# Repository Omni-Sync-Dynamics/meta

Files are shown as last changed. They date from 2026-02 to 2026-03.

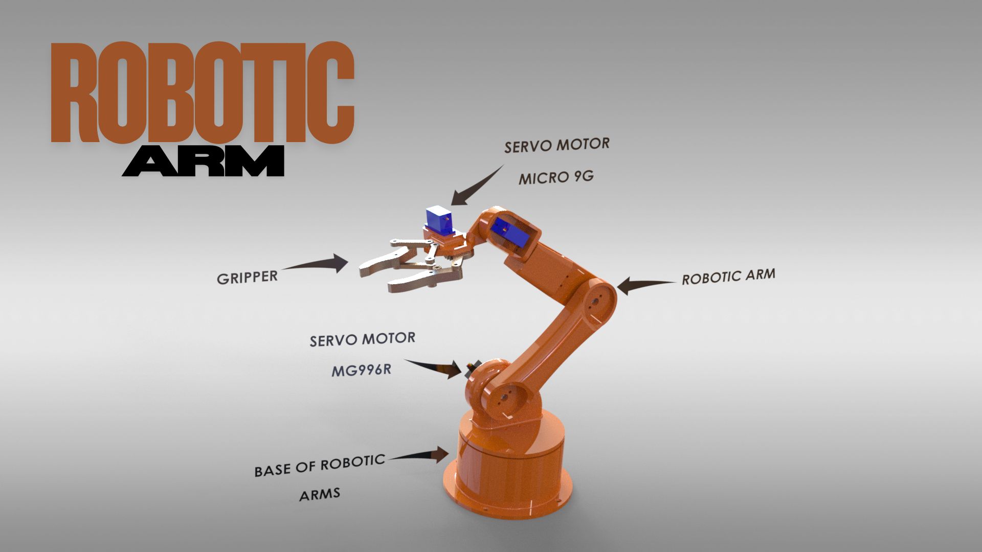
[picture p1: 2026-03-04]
Mechanical/robotic_arm_5dof/isometric_2.jpg

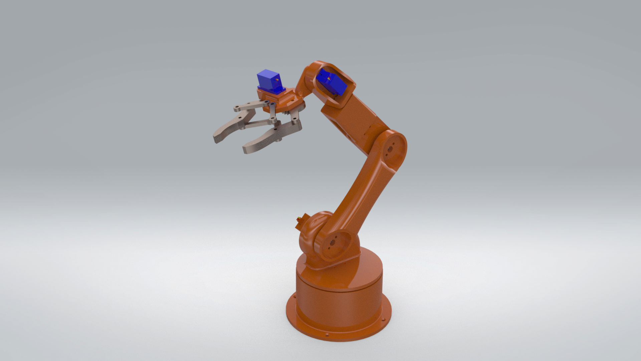
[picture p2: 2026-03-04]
Mechanical/robotic_arm_5dof/isometric.png

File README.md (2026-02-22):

# 🦾 Manipulator Subsystem - Omni-Wheel Mobile Manipulator

**Mechatronics Engineering Department | Faculty of Engineering, Ain Shams University**

This repository contains the mechanical, electrical, and software design files for the **Manipulator Subsystem (Arm & Gripper)** of the Modular Omni-Wheel Mobile Manipulator, developed for the **Spring 2026 Mechatronics Omni-Challenge**.
## 🔭 Overview

The Manipulator Module is designed as a standalone, professionally packaged subsystem. Its primary objective is to autonomously reach, grasp $5\times5\times5$ cm cubes encoded with QR codes from a 40 cm elevated pedestal, identify their color via an integrated camera, and securely place them into specific onboard storage bins.

It acts as the upper layer of the mobile robot and communicates seamlessly with the Mobile Base via a robust CAN/UART interface.

## ✨ Key Features

- **4-DOF Articulated Design:** Optimized to reach the 40 cm pedestal while folding completely within the strict $50\times50\times70$ cm global starting constraint.
    
- **Smart Serial Actuation:** Utilizes daisy-chained smart serial servos (e.g., Dynamixel/Feetech) with built-in absolute encoders and PID control to minimize weight and wire clutter.
    
- **Eye-in-Hand Perception:** Offset end-effector RGB camera paired with an active constant-current LED ring for flicker-free QR code decoding.
    
- **V-Shaped Interlocking Gripper:** Custom parallel-jaw gripper lined with high-friction silicone pads to ensure cubes are not dropped during aggressive omni-directional base maneuvers.
    
- **Custom Integration PCB:** Dedicated onboard PDU and MCU with hardware debouncing, CAN transceivers, and isolated motor power injection.

## 🛠 Hardware Specifications

|Specification|Target / Limit|Notes|
|---|---|---|
|**Degrees of Freedom**|4 (Base, Shoulder, Elbow, Wrist) + 1 (Gripper)|Focused on pick-and-place efficiency.|
|**Max Reach (Horizontal)**|$\ge 40$ cm|Measured from the base joint center.|
|**Payload Capacity**|$250$ g (Nominal) / $500$ g (Max)|For handling $5\times5\times5$ cm cubes.|
|**Module Weight**|$\le 3.0$ kg|Keeps total robot weight under 10 kg.|
|**Operating Voltage**|12V / 24V (Raw)|Stepped down locally to 5V/3.3V.|
|**Comms Protocol**|CAN Bus / RS-485|Optically isolated from motor noise.|

## 🔌 Plug-and-Play Integration

To meet the **< 5-minute integration** constraint, the arm interfaces with the mobile base via a strict modular boundary:

1. **Mechanical:** Chamfered alignment pins and a quick-release latch on the mounting plate.
    
2. **Power:** Single `XT60` or `Anderson Powerpole` connector delivering fused raw battery power.
    
3. **Data:** Single locking `JST-SM` or `Aviation` plug carrying the communication bus lines.
    
4. **Safety:** Software heartbeat watchdog. Loss of comms automatically freezes all servo joints.

## 📂 Repository Structure

```
📦 Manipulator-Subsystem
 ┣ 📂 CAD                 # SolidWorks/Fusion360 assemblies and STL files
 ┣ 📂 Electronics         # KiCAD/Altium schematics and PCB layout files
 ┣ 📂 Software            # ESP32/STM32 firmware (Kinematics, CAN, Safety)
 ┣ 📂 Perception          # Python vision scripts for QR/Color detection
 ┣ 📂 Docs                # VDI 2206 Documentation, FMEA, and Requirements
 ┗ 📜 README.md           # Project overview (This file)
```

## 📚 Documentation

Detailed engineering reports generated following the VDI 2206 methodology:

- [Requirements Analysis Document (`Docs/Requirements.pdf`)](https://www.google.com/search?q=./Docs/ "null")
    
- [System Architecture & FBD (`Docs/Architecture.md`)](https://www.google.com/search?q=./Docs/ "null")
    
- [FMEA Risk Assessment Report (`Docs/Risk_Assessment.pdf`)](https://www.google.com/search?q=./Docs/ "null")
    
- [Electromechanical Bill of Materials (BOM) (`Docs/BOM.pdf`)](https://www.google.com/search?q=./Docs/ "null")
    
- [Electrical & Electronics Architecture (`Docs/Electronics.pdf`)](https://www.google.com/search?q=./Docs/ "null")

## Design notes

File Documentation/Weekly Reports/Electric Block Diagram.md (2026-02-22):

```mermaid
flowchart LR

Battery --> Fuse
Fuse --> PowerBoard

PowerBoard --> MotorDriver1
PowerBoard --> MotorDriver2
PowerBoard --> MotorDriver3
PowerBoard --> MotorDriver4

PowerBoard --> VoltageRegulator

VoltageRegulator --> MCU
VoltageRegulator --> Sensors
VoltageRegulator --> Camera

MCU --> MotorDriver1
MCU --> MotorDriver2
MCU --> MotorDriver3
MCU --> MotorDriver4

Sensors --> MCU
Camera --> MCU
```

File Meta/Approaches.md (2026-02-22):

- Open source
- Mobile robot manipulators
- Omni-wheel platform
- Robotic arm
- Create performance index out of design requirements to compare between different solutions
- Design while learning
- Requirements -> Performance requirements -> FSD (general -> sub systems with reusable functions) -> block diagram and layout
- General brainstorming 
- Meta tasks
- Missing general tasks
- EDP

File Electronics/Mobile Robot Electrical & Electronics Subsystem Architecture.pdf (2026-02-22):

# Mobile Base Module: Electrical &

# Electronics Subsystem Architecture

This document outlines the functional sub-circuits required for the mobile base’s integrated PCB. Designing these as a cohesive onboard system ensures professional packaging, eliminates loose wires, and is strictly required to pass the Phase 1 Safety Check.

### 1 Control Panel Circuit (HMI)

This circuit manages the Human-Machine Interface directly on the robot chassis, handling physical operator inputs and providing immediate system status feedback.

- Mode Switches: Toggle or rotary switches to transition the state machine

between Manual Teleoperation and Autonomous Mode.

- Push Buttons: Hardware buttons (with RC debouncing circuits) for system

resets or specific execution commands.

- Status Indicators: LED arrays with current-limiting resistors to visually in-

dicate Power ON, Fault States, Communication Active, and current operating mode.

### 2 BMS (Battery Management System) Circuit

The BMS acts as the core health monitor for the battery pack. It prevents catastrophic electrical failures and ensures the power source operates within safe margins.

- BMS IC: A dedicated management chip (e.g., BQ series) to monitor individual

cell voltages continuously.

- Balancing Hardware: Cell balancing resistors and MOSFETs to ensure uni-

form voltage across all battery cells during charge and discharge cycles.

- Thermal Sensors: NTC Thermistors placed near the battery leads for real-time

temperature monitoring.

- Current Shunts: Sense resistors to track overall power consumption and detect

over-current stalls.

### 3 Recharging & Power Circuit

This section serves as the main power entry point, routing high current from the battery to the rest of the system while managing the mandatory safe charging approach.

- High-Current Connectors: Secure, polarized connectors (e.g., XT60 or XT90)

bridging the battery and the main board.

- Charge Controller: ICs managing the safe influx of current if onboard charging

is implemented.

- Power Path Management: Power MOSFETs configured to seamlessly and

safely switch between battery power and external wall power during tethered programming or testing.

### 4 Regulation Circuit

Batteries provide a fluctuating voltage that drops as they discharge. This circuit steps down the raw battery voltage into the stable, clean logic levels required by the MCU, sensors, and communication chips.

- Buck Converters (Switching Regulators): High-efficiency circuits (compris-

ing a control IC, inductor, diode, and smoothing capacitors) used to step down the raw battery voltage to a stable 5V for heavier logic loads.

- LDOs (Low Dropout Regulators): Linear regulators used to step down the

5V rail to a highly stable, low-noise 3.3V rail, which is critical for noise-sensitive components like the IMU and MCU.

### 5 Driver & Motor Circuit

This power electronics stage translates low-voltage logic signals from the MCU into high-current outputs to drive the omni-wheel drivechain. Similar to the rapid switching concepts used in AC motor drives, this DC circuit precisely controls speed and torque.

- Power Switching: H-Bridge ICs or discrete power MOSFET arrays to control

the bidirectional rotation of the DC motors.

- Gate Drivers: ICs designed to rapidly switch the MOSFET gates, minimizing

thermal switching losses.

- Flyback Protection: Freewheeling diodes placed across the motor outputs to

protect the circuit from damaging inductive voltage spikes.

- Decoupling: Large electrolytic and ceramic capacitors placed physically close

to the driver ICs to handle sudden, massive current spikes during rapid strafing maneuvers.

### 6 Safety & Protection Circuit

This is the mandatory hardware layer that acts as the ultimate failsafe for the robot. It protects the entire electronics stack from user errors, shorts, and mechanical stalls.

- Main Fuse: An automotive-style blade fuse correctly rated for the combined

maximum current draw of the mobile base and the manipulator.

- Emergency Stop (E-Stop): A physical, latching mushroom button wired di-

rectly in series with the main power line to immediately cut actuation power.

- Reverse Polarity Protection: A P-channel MOSFET or high-current Schot-

tky diode circuit preventing catastrophic damage if the battery is plugged in backward.

- Transient Protection: TVS (Transient Voltage Suppressor) diodes across power

and communication lines to clamp ESD and voltage spikes.

### 7 Sensor & Perception Circuit

This circuit serves as the bridge between the physical environment and the main processor, conditioning signals necessary for precise odometry and autonomous visual perception.

- Camera Interface: A high-speed data bus (such as USB, MIPI CSI, or ded-

icated ribbon connector) connecting an RGB/Depth camera to handle lane detection and color classification via QR code.

- Wheel Motor Encoders: Dedicated headers and signal conditioning (like hard-

ware logic level shifters or Schmitt triggers) to cleanly read high-frequency pulse trains from the quadrature encoders, essential for tracking pure X/Y translation.

- IMU (Inertial Measurement Unit): An onboard sensor IC (e.g., MPU6050)

communicating via I²C/SPI to provide heading stabilization and prevent unin-

tended rotation.

- Optional Interfaces: Headers for extra sensors like proximity/ToF or bump

sensors.

### 8 MCU & Communication Circuit (The Integration Layer)

This circuit houses the “brain” of the base module and the communication bus required for plug-and-play integration with the Manipulator Module.

- Microcontroller Unit (MCU): The primary processor (e.g., ESP32, STM32)

that executes the kinematic controller, state machine, and perception pipelines.

- Minimum System Components: The external crystal oscillator (clock), boot

configuration resistors, and reset circuitry required for the MCU to function.

- Communication Transceivers (COM Circuit): ICs specific to your chosen

protocol (e.g., CAN transceiver like the MCP2551, or RS-485 driver) to enable a robust comms bus between the base and the arm.

- Isolation: Opto-isolators to electrically separate logic signals between the base

and manipulator, preventing ground loops and motor noise from corrupting data.

- Standardized Connectors: Locking headers (e.g., Molex or JST) forming the

physical standardized electrical interface for the plug-and-play requirement.

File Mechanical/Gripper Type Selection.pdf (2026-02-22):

## Gripper Type Selection

Gripper types
1) Parallel jaw

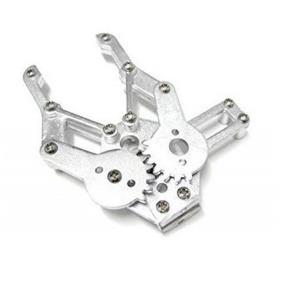
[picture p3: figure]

2) 3 fingers

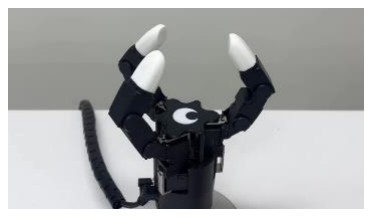
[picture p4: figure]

3) Adaptive

Note: Other gripper types such as magnetic and suction-based grippers were considered but excluded from the comparison for the following reasons:
- Magnetic grippers are not suitable because the cubes
are made of plastic and contain no ferromagnetic
materials.

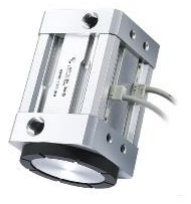
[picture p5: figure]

- Suction cup grippers require an external air supply (e.g., compressor or vacuum pump), which would add significant weight, complexity, and power consumption to the mobile robot, making them impractical for this application.

Comparison
Criteria | Definition | Weight | Parallel jaw | 3 fingers | Adaptive
Simplicity | Number of moving parts | 15% | 14 | 11 | 7
Ease of design | Estimated design time (hrs) | 10% | 10 | 6 | 4
Ease of manufacturing | 3D printable? | 15% | 13 | 12 | 11
Stability | Contact points | 20% | 12 | 15 | 18
Weight | Mass (grams) | 25% | 22 | 20 | 13
Coat | | 15% | 15 | 13 | 10
Total | - | 100% | 86 | 77 | 63

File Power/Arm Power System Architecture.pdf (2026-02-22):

# Manipulator Module: Electrical & Electronics Subsystem Architecture

This document outlines the highly integrated, functional sub-circuits required for the Manipulator Module’s dedicated Printed Circuit Board (PCB) and electronic routing. Designing these as a cohesive onboard system ensures professional packaging, mitigates electromagnetic interference (EMI), and eliminates loose wiring. This architecture strictly adheres to the Phase 1 Safety Check requirements and the sub-5-minute plug-and-play integration constraint dictated by the VDI 2206 design methodology.

## 1 Power Distribution & Protection Circuit (PDU)

Unlike the base, the arm does not house the main battery. This circuit manages the raw power received from the base, utilizing hot-swap methodologies to protect the arm’s sensitive logic components and safely distribute high current to the dynamic actuators.

- Standardized Hot-Swap Input: A high-current locking connector (e.g., XT60 or Anderson Powerpole) serves as the primary interface. An inrush current limiter (eFuse IC or NTC thermistor) is implemented to prevent connector sparking and voltage sags during plug-and-play attachment.
- Advanced Local Protection: A fast-acting automotive blade fuse rated specifically for the arm’s maximum stall current. This is paired with a P-Channel MOS-FET ideal diode circuit for negligible voltage-drop reverse polarity protection, and TVS (Transient Voltage Suppressor) diodes to clamp inductive voltage spikes generated by the base’s traction motors.
- Synchronous Step-Down Converters (Buck): High-efficiency switching regulators featuring integrated LC filters to drop the raw 12V/24V bus voltage down to ultra-stable logic levels (3.3V for the MCU/Sensors and 5V for the camera/logic ICs).
- Galvanically Isolated Motor Power Injection: Heavy copper pours (2 oz/ft² )
and dedicated wide traces route high-current raw power directly to the servo headers. The motor ground return path is physically separated from the logic ground on the PCB to prevent ground bounce.

## 2 Actuator & Limit Switch Interface Circuit

This circuit bridges the high-level logical commands from the MCU to the physical electromechanical joints and gripper, ensuring real-time, deterministic control.

- Smart Servo Half-Duplex Bus: 3-pin or 4-pin headers (Power, GND, Data) designed to daisy-chain serial servos (e.g., Dynamixel or Feetech). The circuit utilizes a tri-state buffer IC (e.g., 74LVC1G126) to cleanly convert the MCU’s standard fullduplex UART (Tx/Rx) into the single-wire half-duplex signal required by industrial smart servos.
- Opto-Isolated Gripper PWM Output: A dedicated header to drive the micro-servo responsible for the V-shaped interlocking gripper fingers. The PWM signal is passed through an optocoupler to ensure back-EMF from the cheap micro-servo does not damage the main MCU.
- Hardware Debounced Limit Switch Inputs: Headers for physical end-stop/homing switches. To ensure zero false-triggers from motor noise, the inputs pass through an RC low-pass filter followed by an inverting Schmitt Trigger IC (e.g., 74HC14), feeding perfectly crisp digital edge interrupts to the MCU.

## 3 Perception & Lighting Circuit

This section manages the end-effector components strictly required for the autonomous, vision-based QR-code reading segment of the competition.

- High-Speed Camera Interface: A high-speed data routing path (USB 3.0 Type-C or MIPI CSI-2 via FPC cable) connecting the offset end-effector RGB camera. Differential pairs are routed with strict 90Ω impedance matching to prevent data packet loss. This data bypasses the Arm MCU and routes directly to the Base Perception SoC.
- Constant-Current LED Driver: Instead of a basic PWM MOSFET, a dedicated constant-current buck LED driver (e.g., AL8805) powers the active LED ring light. This provides flicker-free illumination, which is absolutely critical to prevent rollingshutter artifacts on the camera sensor during QR decoding under varying ambient track lighting.

## 4 MCU & Communication Circuit (Integration Layer)

This circuit houses the ”brain” of the manipulator module and the robust communication bus required for seamless plug-and-play synchronization with the mobile base.

- Microcontroller Unit (MCU): A high-performance local processor equipped with a Hardware Floating-Point Unit (FPU) (e.g., STM32F4/F7 series or Teensy 4.0). The FPU is mandatory for computing complex 3D Inverse Kinematics (IK) matrices and joint trajectory profiling in real-time (> 100 Hz loop rate).

- Isolated CAN Bus Transceiver: The inter-module communication utilizes the Controller Area Network (CAN) protocol due to its extreme fault tolerance. A galvanically isolated CAN transceiver (e.g., ISO1050) is used alongside a 120Ω termination resistor. This electrically separates the base and arm, preventing noise from traction motors from corrupting the arm’s target pose packets.
- Safety Heartbeat Watchdog: An independent hardware watchdog timer configured to trigger if the CAN bus heartbeat from the Base SoC is lost for more than 100ms, immediately pulling the smart servo enable lines low to freeze the arm in a safe state.

## 5 PCB Layout & EMI/EMC Guidelines

To guarantee reliability in a high-noise mechatronic environment, the Manipulator Module’s custom PCB will be designed adhering to strict electromagnetic compatibility (EMC) standards:

- Star Grounding Topology: Motor power grounds and logic logic grounds will only tie together at one single point (at the buck converter’s ground pad) to completely eliminate ground loops.
- Decoupling Strategy: A generous array of 0.1µF and 10µF MLCC capacitors will be placed as physically close as possible to every IC’s power pins to supply instantaneous current demands and filter high-frequency noise.

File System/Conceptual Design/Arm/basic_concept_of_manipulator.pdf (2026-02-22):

# Basic Concept of Manipulator Subsystem

# Hardware Architecture and Specification Compliance Report

### Course: MCT333/MCT344 - Mechatronic System Design

### Competition: Spring 2026 Mechatronics Omni-Challenge

### February 21, 2026

Abstract

This document outlines the proposed hardware architecture for the Manipulator Subsystem of the Spring 2026 Mechatronics Omni-Challenge. It details the selection of Smart Serial Servos for actuation to minimize weight and wiring complexity, a 4-DOF articulated arm design for optimal reach and foldability, and an offset end-effector perception module. Furthermore, this document demonstrates how these design choices comply with the official project specifications regarding modularity, strict dimensions (50 × 50 × 70 cm starting constraint), weight limits, and safety.

## Contents

1 Actuation System Selection | 2
2 Kinematic and Arm Design Concepts | 2
3 End-Effector and Perception Architecture | 3
4 Safety and Modularity Interface | 3
5 Compliance Matrix | 3
6 Next Steps | 4

## 1 Actuation System Selection

### 1.1 Trade-off Analysis

During the concept generation phase, the team evaluated three primary actuation systems for the robotic arm joints:

1. Stepper Motors with Drivers: High holding torque and precision, but significantly heavier. Requires complex homing routines with external limit switches and bulky multi-wire harnesses.
2. DC Motors with Encoders: Fast and potentially lightweight, but requires complex custom PID tuning, large gearboxes for necessary torque, and separate heavy motor driver boards.
3. Smart Serial Servos (e.g., Dynamixel, Feetech): High torque-to-weight ratio, built-in absolute encoders, built-in PID control, and daisy-chainable wiring (requires only 3 or 4 wires to run through the entire arm).

### 1.2 Final Decision

Smart Serial Servos were selected. The daisy-chaining capability is crucial for meeting the “sub-5-minute plug-and-play” requirement, as it radically simplifies the electrical interface between the base and the arm. Furthermore, their lightweight nature ensures the manipulator mass remains well below the 3 kg target, preserving the overall 10 kg limit and keeping the robot’s center of gravity low.

## 2 Kinematic and Arm Design Concepts

### 2.1 Idea 1: Anthropomorphic 5-DOF Arm

A highly flexible design capable of complex 3D maneuvers. However, the extra joints add unnecessary weight, increase the complexity of the Inverse Kinematics (IK) solver, and make it difficult to reliably fold within the 50 × 50 × 70 cm starting bounding box.

### 2.2 Idea 2: 4-DOF Selective Articulated Arm (Selected)

A streamlined 4-DOF configuration (Base Pan, Shoulder Pitch, Elbow Pitch, Wrist Pitch/Roll) focused on reaching the 40 cm pedestal and dropping cubes into the onboard bins.

- Reach: Link lengths are optimized to extend ≥ 40 cm horizontally and clear the
40 cm vertical pedestal height.
- Foldability: The arm is designed to fold back onto itself (similar to an excavator arm) to easily fit within the 50 × 50 × 70 cm constraint.
- Material: Links will be fabricated using lightweight 3D printed PETG/ABS reinforced with carbon fiber tubes to prevent tip deflection.

## 3 End-Effector and Perception Architecture

### 3.1 Gripper Mechanism

To handle the 5×5×5 cm cubes securely without dropping them during omni-directional strafing, a parallel jaw gripper with V-shaped interlocking fingers is selected. The fingers will be lined with high-friction silicone pads to ensure the cubes do not slip.

### 3.2 Perception Integration (Eye-in-Hand)

A local RGB camera must be mounted to read the QR codes on the cubes.

- Placement: Mounted directly on the end-effector (Eye-in-Hand) using an offset bracket.
- Rationale: The offset bracket ensures the gripper fingers do not physically obstruct the camera’s Field of View (FOV) when approaching the cube. An active LED ring will be added to guarantee consistent lighting for QR decoding.

## 4 Safety and Modularity Interface

Modularity is a core requirement of the Spring 2026 competition. The manipulator will interface with the lower base via a strictly defined layer:

- Mechanical: A standardized base plate utilizing chamfered alignment pins and a quick-release latch to ensure attachment in under 5 minutes.
- Electrical: A centralized power connector (XT60) passing fused 12V/24V power, and a single communication connector (JST/Aviation) passing the CAN or UART bus signals.
- Safety Fallback: The Arm MCU will implement a software heartbeat. If communication with the Base SoC is lost, the smart servos will automatically enter a torque-hold (freeze) state to prevent the arm from collapsing.

## 5 Compliance Matrix

The following table maps our proposed design features to the specific constraints listed in the MCT333 Project Description.

Design Feature | Project | Require-
| ment

Status

4-DOF Foldable Kinematics

Max | folded | dimen-
sions: 50 × 50 × 70 cm

Compliant

Link Length Optimization

Reach 40 cm elevated
pedestal

Compliant

Quick-Release Base
Plate

Plug-and-play integration in < 5 minutes

Compliant

Smart Serial Servos Minimize weight (< 10 kg total system limit)

Compliant

Offset Camera Bracket Unobstructed QR code color classification

Compliant

V-Shaped Silicone
Gripper

Secure grasp of 5×5×5
cm cubes

Compliant

Heartbeat | & | Fused
Power

Phase 1 Safety Gate
(No uncontrolled motion)

Compliant

## 6 Next Steps

1. CAD Validation: Verify the 4-DOF arm kinematics and confirm the folded configuration fits within the 50 × 50 cm footprint using CAD software.
2. Actuator Sizing: Calculate the maximum static holding torque required at the shoulder joint when the arm is fully extended with a 250 g payload.
3. Interface Prototyping: 3D print and test the quick-release mechanical mating plate.
4. Vision Testing: Prototype the offset camera bracket and test QR code reading reliability under various lighting conditions.

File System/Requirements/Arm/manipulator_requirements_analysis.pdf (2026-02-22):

# Modular Omni-Wheel Mobile Manipulator

# Manipulator Subsystem: Requirements Analysis Document

### Course: MCT333/MCT344 - Mechatronic System Design

### Competition: Spring 2026 Mechatronics Omni-Challenge

### February 21, 2026

## Contents

1 Introduction | 2
2 System Overview | 2
3 Mechanical Requirements | 2
4 Electrical and Electronics Requirements | 3
5 Power System Requirements | 4
6 Control and Software Requirements | 4
7 Interface and Modularity Requirements | 5
8 Safety Requirements | 5

## 1 Introduction

This document defines the system-level requirements for the Manipulator Subsystem (Arm and Gripper Module) of the Modular Omni-Wheel Mobile Manipulator developed for the Spring 2026 Mechatronics Omni-Challenge.
The Manipulator Subsystem consists of:
- A multi-degree-of-freedom (DOF) robotic arm.
- An end-effector (gripper) designed for specific competition objects.
- Local perception (camera) and dedicated arm control circuitry.
- Modular plug-and-play mechanical and electrical interfaces.

The requirements below are derived from the official competition document, focusing strictly on the manipulator’s standalone functionalities and its integration with the mobile base.

## 2 System Overview

The Manipulator Module must operate as an independent, professionally packaged subsystem. Its primary objective is to autonomously reach, grasp 5×5×5 cm cubes (encoded with QR codes) from a 40 cm elevated pedestal, identify their color via an integrated camera, and securely place them into specific onboard storage bins. It must achieve this while maintaining a lightweight profile and communicating seamlessly with the main mobile base.

## 3 Mechanical Requirements

### 3.1 Arm Structure & Kinematics

- Degrees of Freedom (DOF): Minimum of 4 DOF (e.g., Base Pan, Shoulder Tilt, Elbow Tilt, Wrist Pitch/Roll) to successfully pick from the pedestal and place into onboard storage bins.
- Workspace (Reach Volume):

– Maximum horizontal reach: ≥ 40 cm from the center of the arm’s base to the end-effector.

– Maximum vertical reach: ≥ 45 cm from the robot’s mounting plate to comfortably clear the 40 cm competition pedestal.

– Folded State: Must fold completely into the robot’s 50 cm (W) × 50 cm (L) × 70 cm (H) starting volume footprint.

- Payload Capacity:

– Nominal Payload: ≥ 250 g (accommodates a standard 5 × 5 × 5 cm plastic cube with a factor of safety).

– Maximum Payload (Stall Limit): ≥ 500 g at maximum horizontal extension.

- Kinematic Performance:

– Repeatability: ±5 mm at the end-effector to ensure reliable QR-code alignment and placement.

– End-Effector Velocity: Capable of operational linear speeds up to 15 cm/s during autonomous trajectories.

- Mass Constraints: Total manipulator mass (including gripper and local electronics) must be ≤ 3 kg to preserve the mobile base’s center of gravity and respect the 10 kg global weight limit.

### 3.2 Gripper & End-Effector

- Grasp Dimension (Stroke): Maximum jaw opening must be ≥ 7 cm to comfortably approach the 5 × 5 × 5 cm target cubes despite minor odometry errors.
- Grip Force: Must exert a sustained gripping force of ≥ 10 N (≈ 1 kg equivalent) without crushing or deforming the objects.
- Geometric Constraints: Must not physically obscure the face of the cube containing the QR code during the approach or grasping phases. Minimum camera viewing angle clearance (> 60◦ FOV) must be maintained.
- Dynamic Stability: Must maintain grip during fast omni-directional base movements (e.g., sudden braking or strafing) without dropping the payload.

### 3.3 Base Integration

- Must feature a standardized mechanical mounting pattern (e.g., base plate with alignment pins and quick-release fasteners).
- Must support attachment/detachment in under 5 minutes.

## 4 Electrical and Electronics Requirements

### 4.1 Control Hardware

- Must contain its own dedicated MCU/Controller (e.g., ESP32, STM32, Arduino) independent of the base’s navigation controller.
- Must include necessary motor drivers or interface logic for smart serial servos.

### 4.2 Sensors

- Vision: Must integrate a camera (RGB) positioned to clearly read QR codes on the cubes.
- Proprioception: Must include joint encoders (absolute or incremental) to track arm position accurately.

- Limits: Must include physical limit switches or hard-stops for homing and overtravel protection.

### 4.3 Communication

- Internal communication bus (e.g., UART, I2C, SPI) for sensors and actuators.
- External communication bus (e.g., CAN, RS-485, Ethernet) to receive high-level commands from the Integration Layer / Base.

## 5 Power System Requirements

### 5.1 Power Source Integration

- Must receive raw power from the Mobile Base Module via a standardized power connector.
- Must not require a separate dedicated battery unless explicitly justified by modularity limits.

### 5.2 Power Electronics

- Must include local voltage regulation (Buck converters) to provide stable 3.3V/5V for the arm’s logic, MCU, and camera.
- Must distribute high-current power safely to the joint actuators.

### 5.3 Circuit Protection

- Must include local fusing specifically rated for the arm’s maximum current draw.
- Must include reverse polarity protection at the plug-and-play power input.

## 6 Control and Software Requirements

- Kinematic Engine: Software must actively compute Forward and Inverse Kinematics to translate XYZ coordinates into joint angles.
- Trajectory Planning: Must implement smooth motion profiles (e.g., S-curve or trapezoidal) to prevent jerking and payload dropping.
- State Machine: Must possess operating states (Folded, Homing, Reaching, Grasping, Storing) controlled by the main base via the communication bus.
- Safety Fallback: Must automatically freeze all joint movements if the communication heartbeat from the base is lost.
- Perception Pipeline: Must capture camera frames and either process the QR code locally or stream the feed reliably to the main base SoC for processing.

## 7 Interface and Modularity Requirements

- Electrical Interface: Standardized power connector (e.g., XT60) and standard data connector (e.g., JST, Aviation plug) to enable plug-and-play.
- Protocol: Well-defined communication protocol including heartbeat, target pose commands, and current joint state feedback.
- Wiring Management: No exposed wires. Wires crossing joints must have strain relief and ideally be routed through drag chains or protective sleeving.
- Assembly Time: Full mechanical and electrical integration with the mobile base must be provable within a 5-minute window.

## 8 Safety Requirements

To pass the Phase 1 Safety Gate, the Manipulator Module must ensure:

- No hanging or exposed wires that could catch on the track or the robot base.
- No sharp edges or unsafe protrusions on the gripper or linkages (de-burred and covered).
- Software joint limits strictly enforced to prevent self-collision with the base or the camera.
- PCB and electronics are securely mounted within an enclosure, isolated from moving metal parts.

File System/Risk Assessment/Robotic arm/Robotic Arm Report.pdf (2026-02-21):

## Manipulator Subsystem: Risk Assessment Report

Mechatronics Omni-Challenge - Spring 2026

Subsystem: Arm / Manipulator Module

February 21, 2026

## 1 Introduction

This document outlines the risk assessment process and results for the Manipulator Subsystem of the Modular Omni-Wheel Mobile Manipulator. The goal of this Failure Mode and Effects Analysis (FMEA) style report is to proactively identify, analyze, and evaluate potential mechanical, electrical, software, and perception risks to minimize their negative impact on project performance, safety, and competition constraints.

## 2 Risk Assessment Matrix

The risk score R is calculated by the product of Likelihood (L) and Impact (I):

R = L × I | (1)

Priority is determined by the following scale:

L | Description | I | Description | Score (R) | Risk Level
1 | Rare | 1 | Insignificant | 1 – 4 | Low
2 | Unlikely | 2 | Minor | 5 – 9 | Medium
3 | Moderate | 3 | Moderate | 10 – 14 | High
4 | Likely | 4 | Major | 15 – 20 | Extreme
5 | Almost Certain | 5 | Catastrophic | 21 – 25 | Extreme

## 3 Identified Risks and Mitigation Strategies

### 3.1 Mechanical Risks (M)

Focuses on physical structure, spatial constraints, and gripper dynamics.
ID | Risk Description | L | I | R | Level | Mitigation Strategy
M-001 | Arm tip deflec-tion/oscillation | 4 | 3 | 12 | High | Use carbon fiber; S-curve profiling.
M-002 | Base joint mechanical failure | 2 | 5 | 10 | High | Use thrust bearings; metal brackets.
M-003 | Exceeding dimension con-straints | 2 | 5 | 10 | High | Foldable kinematic chain; Week 3 CAD check.
M-005 | Wire tangling or snapping | 4 | 4 | 16 | Extreme | Internal routing; drag chains; silicone wire.

1

### 3.2 Electromechanical Risks (E)

Concerns the intersection of control and physical output (torque/thermals).
ID | Risk Description | L | I | R | Level | Mitigation Strategy
E-001 | Motors undersized for reach | 3 | 5 | 15 | Extreme | Static torque calcs; counter-weights.
E-002 | Actuator overheating (static) | 3 | 4 | 12 | High | Current reduction; worm gears.
E-003 | Gearbox backlash | 4 | 3 | 12 | High | Planetary gears; absolute output encoders.

### 3.3 Electrical & Power Risks (P)

Concerns power distribution and signal integrity.
ID | Risk Description | L | I | R | Level | Mitigation Strategy
P-001 | MCU Brownout on high load | 4 | 5 | 20 | Extreme | Isolate logic/motor rails; by-pass caps.
P-003 | Signal noise (I2C/SPI) | 4 | 4 | 16 | Extreme | Twisted pairs; shielded ca-bles; CAN bus.

### 3.4 Software & Control Risks (S)

Concerns kinematics, safety states, and communication.
ID | Risk Description | L | I | R | Level | Mitigation Strategy
S-001 | Self-collision/Hard stops | 3 | 5 | 15 | Extreme | Software limits; physical limit switches.
S-003 | Comms timeout (Heartbeat) | 3 | 4 | 12 | High | 10Hz ping; safe-state motor freeze.

### 3.5 Perception Risks (C)

Integration of sensors and QR vision systems.
ID | Risk Description | L | I | R | Level | Mitigation Strategy
C-001 | QR lighting/shadow failure | 3 | 5 | 15 | Extreme | Active LED ring; auto-exposure pipeline.
C-002 | Gripper obstructs camera FOV | 4 | 4 | 16 | Extreme | FOV modeling in CAD; off-set mounting.

2

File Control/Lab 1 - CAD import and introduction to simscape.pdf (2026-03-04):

Spring 2026

Lab Session 01: Linking Inventor and Simscape Multibody

Contents*

1- Installing the Simscape Multibody Link Plugin 2- Exporting a 3D assembly from Solidworks
3- Exporting a 3D assembly from Inventor
4- Importing an exported 3D assembly to Simscape Multibody
5- Considerations for converting from CAD software to Simscape Multibody 6- Mechatronics system design and modelling using Simscape Multibody
Background

Simscape™ Multibody™ Link is a plug-in that you install on your CAD application to export your CAD assembly models. The plug-in generates the files that you need to import the model into the Simscape Multibody environment (using the smimport function). You can install the plug-in on three CAD applications:

- SolidWorks®
- Autodesk Inventor®
- PTC® Creo™

The plug-in generates an XML file detailing the structure and properties of your CAD assembly and 3-D geometry files for visualizing the various CAD parts. You can then import the files into Simscape Multibody software, which parses the XML data and automatically generates an equivalent multibody model.

Exercise 1: Install Simscape Multibody Link Plug-In.

Before You Begin
You must have one of the supported CAD applications:
- Autodesk Inventor software
- PTC Creo software
- SolidWorks software
Your MATLAB and CAD installations must have the same system architecture—e.g., Windows 64-bit.
Step 1: Get the Installation Files
1. Go to the Simscape Multibody Link download page. (http://www.mathworks.com/products/simmechanics/download_smlink.html)
2. Follow the prompts on the download page.
3. Save the zip archive and MATLAB file in a convenient folder.
Select the file versions matching your MATLAB release number and system architecture—e.g., release R2016a and Win64 architecture. Do not extract the zip archive.
Step 2: Run the Installation Function
1. Run MATLAB as administrator.
2. Add the saved installation files to the MATLAB path.
You can do this by entering addpath('foldername') at the MATLAB command prompt. Replace foldername with the name of the folder in which you saved the installation files—e.g., C:\Temp.
3. At the MATLAB command prompt, enter install_addon('zipname').
Replace zipname with the name of the zip archive—e.g., smlink.r2015b.win64.zip.

*Parts of this lab sheet are based on the Simscape Multibody documentation, provided by Mathworks

# MCT 333: Mechatronic System Design

AIN SHAMS UNIVERSITY
FACULTY OF ENGINEERING
MECHATRONICS ENGINEERING DEPARTMENT

Step 3: Register MATLAB as an Automation Server
Each time you export a CAD assembly model, the Simscape Multibody Link plug-in attempts to connect to MATLAB. For the connection to occur, you must register MATLAB as an automation server. You can do this in two ways:
- In a MATLAB session running in administrator mode — At the command prompt, enter regmatlabserver
- In an MS-DOS window running in administrator mode — At the command prompt, enter matlab -regserver.
Step 4: Enable the Simscape Multibody Link Plug-In
Before you can export an assembly, you must enable the Simscape Multibody Link plug-in on your CAD application. To do this, see:
- Enable Simscape Multibody Link Inventor Plug-In
1. At the MATLAB® command prompt, enter smlink_linkinv.
2. A Simscape Multibody Link menu appears in the Inventor menu when you start or open a CAD assembly.

If your computer has more than one Inventor application, the smlink_linkinv command adds the Simscape Multibody Link plug-in to all installations simultaneously.

- Enable Simscape Multibody Link SolidWorks Plug-In
1. At the MATLAB® command prompt, enter smlink_linksw.
2. Start SolidWorks.
3. In the Tools menu, select Add-Ins.

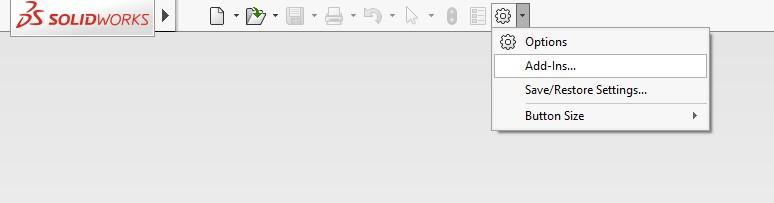
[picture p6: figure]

4. In the Add-Ins dialog box, select the Simscape Multibody Link check box. A Simscape Multibody Link menu appears in the SolidWorks menu bar when you start or open a CAD assembly.

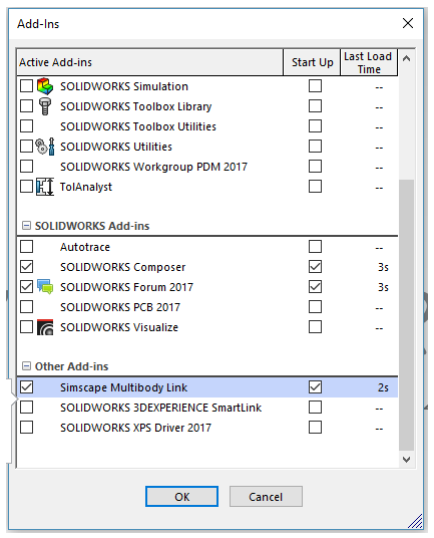
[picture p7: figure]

If your computer has more than one SolidWorks installation, the smlink_linksw command adds the Simscape Multibody Link plug-in to all installations simultaneously. However, you must select the Simscape Multibody Link check box in the Add-Ins dialog box individually for each installation you want to export CAD from.

Exercise 2: Export a CAD mechanism drawn on Inventor to Simscape Multibody.

In this example, you export an Autodesk Inventor® CAD assembly that represents a robot arm. The export procedure generates one XML file and a set of geometry files that you can import into Simscape™ Multibody™ to generate a new s model.
The example begins with a procedure to export the CAD assembly. Information on the robot CAD files and CAD Export follows the export procedure

The Robot Assembly Model

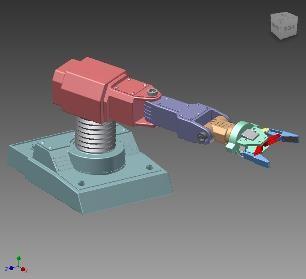
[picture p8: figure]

Open the Assembly Model
Before you can export the robot assembly, you must load the assembly into Inventor.
1. Open Inventor on your machine.

### 2. Select File > Open

3. Navigate to the file directory that contains the robot CAD files.
Note: The directory that contains the robot CAD files for the Autodesk Inventor platform is <MATLAB Root>\toolbox\physmod\smlink\smlinkdemos\inventor\robot
Where <MATLAB Root> for R2016a is usually C:\Program files\MATLAB\R2016a
4. Select file robot.IAM.
5. Click Open.

The CAD platform opens the robot assembly.

Export the Model
Once you successfully open the robot CAD assembly in your Inventor installation, you can export the assembly in a format compatible with the latest Simscape Multibody technology:
1. In the Inventor toolbar, select Add-Ins > Export Simscape Multibody.

2. In the File name field of the Save As dialog box, enter sm_robot and select a suitable directory to export the files. For example, save it to the desktop under a folder called robot
3. Click Save.
Note: Large CAD assemblies require more time to complete the export process. Allow up to a few minutes for the export process to complete.

Check the Exported Files
Confirm the following files exist in the export directory you specified:
- XML file—Provides structure of model and parameters of parts.
- Geometry files—Provide surface geometry of parts.

About the Example CAD Files
The CAD assembly files are present in your Simscape Multibody Link installation. You can access the files in the following directory:
<MATLAB Root>\matlab\toolbox\physmod\smlink\smlinkdemos\inventor\robot
Substitute <MATLAB Root> with the root directory of your MATLAB® installation.
Note: If you are not sure what your MATLAB root directory is, at the MATLAB command line enter matlabroot. MATLAB returns the root directory for your installation.

The \inventor\robot directory contains a set of CAD files that define each CAD part and CAD assembly. Part file names contain the file extension .IPT. Assembly file names contain the extension .IAM.
The robot assembly contains nine parts and two assemblies: robot.IAM and grip.IAM. File robot.IAM models the robot root assembly. File grip.IAM models the robot grip subassembly.

About CAD Export
The CAD export procedure generates one XML multibody description file and a set of geometry files. The XML file contains the structure of the assembly and the parameters that define each part. The geometry files define the 3-D surface of each part. Once the export procedure is complete, you can import the XML multibody description file into Simscape Multibody software. Simscape Multibody uses the file to automatically generate a new Simscape Multibody model.

Exercise 3: Import an xml of a CAD mechanism generated using the Link plugin into Simscape Multibody.
This example shows how to generate a Simscape™ Multibody™ model from a multibody description XML file using the smimport function. The example is based on a multibody description file that you exported in Exercise 2.
Import the Model
1. In MATLAB, navigate to the folder that you saved in Exercsise 2.
2. At the MATLAB command prompt, enter the command:
smimport('sm_robot');
Simscape Multibody software generates the model described in the sm_robot.xml file using the default smimport (https://www.mathworks.com/help/physmod/sm/ref/smimport.html) function settings.

The blocks in the generated model are parameterized in terms of MATLAB variables. The numerical values of these variables are defined in a data file that is named sm_robot.m and stored in the same active folder as the generated model.

Visualize the Model
Update the diagram to visualize the model. You can do this from the Simulink® menu bar by selecting Simulation > Update Diagram. Mechanics Explorer opens with a static visualization of the robotic arm model in its initial configuration.

The default view convention in Mechanics Explorer differs from that in the CAD application used to create the original assembly model. Mechanics Explorer uses a Z-axis-up view convention while the CAD application uses a Y-axis-up view convention.
Change the view convention from the Mechanics Explorer toolstrip by setting the View convention parameter to Y up (XY Front). Then, select a standard view from the View > Standard Views menu to apply the new view convention.

Build on the Model

Try to simulate the model. Because the robotic arm lacks a control system, it simply flails under gravity. You can use Simulink blocks to create the control system needed to guide the robotic arm motion. A control system would convert motion sensing outputs into actuation inputs at the various joints. You can expose the sensing and actuation ports from the joint block dialog boxes.

Exercise 4: Translating a CAD Model to a Simscape Multibody model

You can translate a CAD model into an equivalent Simscape™ Multibody™ block diagram. The conversion relies on the smimport function featuring an XML multibody description file name as its central argument. The XML file passes to Simscape Multibody software the data it needs to recreate the original model—or an approximation of it if unsupported constraints exist in the model.
You translate a CAD model in two steps—export and import. The export step converts the CAD assembly model into an XML multibody description file and a set of STEP or STL part geometry files. The import step converts the multibody description and part geometry files into an SLX Simscape Multibody model and an M data file. The model obtains all block parameter inputs from the data file.
CAD Translation Steps

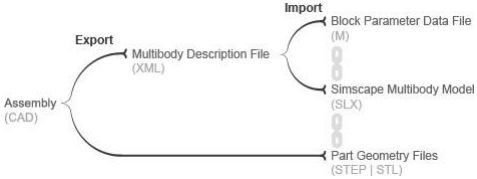
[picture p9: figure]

What’s in a Translated Model?
The translated model represents the CAD parts—referred to as bodies in Simscape Multibody software— using Simulink® subsystems that comprise multiple Solid (https://www.mathworks.com/help/physmod/sm/ref/solid.html) and Rigid Transform (https://www.mathworks.com/help/physmod/sm/ref/rigidtransform.html) blocks. The Solid blocks provide the body geometries, inertias, and colors. The Rigid Transform blocks provide the frames with the required poses for connection between bodies.

Consider the upper arm body of a CAD robotic arm model, shown in the figure. The Simulink subsystem for this body consists of one Solid block connected to a pair of Rigid Transform blocks. The Solid block provides the reference to the upper arm geometry file and the inertial properties derived from the CAD model. The Rigid Transform blocks provide the frames for connection to the robot base and lower arm bodies.
Simulink Subsystem Representing Upper Arm Body

CAD joints, constraints, and mates translate into Simscape Multibody software as combinations of joint and constraint blocks. In the CAD robotic arm example, the constraints between the upper arm and the lower arm translate into a Revolute Joint block. This block sits between the Simulink Subsystem blocks that represent the upper arm and lower arm bodies.
Simulink Subsystem Representing Upper Arm Body

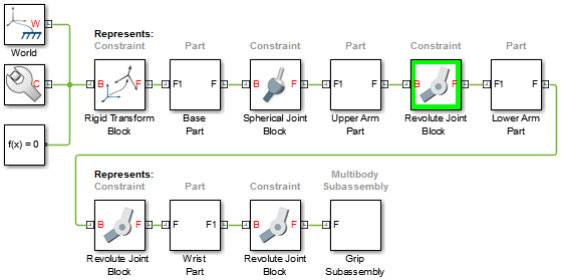
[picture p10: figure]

Important:
By default, the translated model preserves the structural hierarchy of the original CAD model. If the source model is a CAD model with multibody subassemblies, the subassemblies convert in Simscape Multibody software into multibody Simulink subsystems. Consider again the CAD robotic arm model. The model contains a grip multibody subassembly with seven bodies, shown schematically in the figure.

CAD Robotic Arm Model Hierarchy

During translation, the grip subassembly converts into a Simulink subsystem with seven Simulink subsystems, one for each body.
Multibody Simulink Subsystem with Body Simulink Subsystems

What’s in a Data File?
Blocks in the translated model are parameterized in terms of MATLAB® variables defined in the data file. These variables are stored in structure arrays named after the various block types. The structure arrays are nested in a parent data structure named smiData or a custom string that you specify.
Consider an imported model with a data structure named smiData. If the model contains Revolute Joint (https://www.mathworks.com/help/physmod/sm/ref/revolutejoint.html) blocks, the parameter data for these blocks is the structure array smiData.RevoluteJoint. This structure array contains a number of data fields, each corresponding to a different block parameter.
The structure array fields are named after the block parameters. For example, the position state target data for the Revolute Joint blocks is in a field named Rz_Position_Target. If the model has two Revolute Joint blocks, this field contains two entries—smiData.RevoluteJoint(1).Rz_Position_Target and smiData.RevoluteJoint(2).Rz_Position_target.
Each structure array index corresponds to a specific block in the imported model. The index assignments can change if you regenerate a data file from an updated XML multibody description file. The smimport (https://www.mathworks.com/help/physmod/sm/ref/smimport.html) function checks the prior data file, when specified, to ensure the index assignments remain the same.

Exporting a CAD Model
You can technically export a CAD assembly model from any CAD application. The Simscape Multibody Link CAD plug-in provides one means to export a model in a valid XML format. The plug-in is compatible with three desktop CAD applications: SolidWorks®, PTC® Creo™, and Autodesk® Inventor®. The plug-in generates not only the XML multibody description file but also any geometry files required for visualization in the final translated model.
If you use an unsupported CAD application and a URDF converter exists for your CAD application, you may be able to export your model in URDF format and import the URDF file into the Simscape Multibody environment. Note, however, that the URDF specification forbids closed-chain model topologies, such as those of four-bar linkages and gear assemblies. For more information, see URDF Import (https://www.mathworks.com/help/physmod/sm/ug/urdf-import.html) (Simscape Multibody).

A Note About Export Errors
If the Simscape Multibody Link plug-in cannot export a part geometry file or translate a CAD constraint set, the software issues an error message. The error message identifies the bodies with missing geometry files and any unsupported constraints. You can import the generated XML multibody description file into Simscape Multibody software, but the resulting model may not accurately represent the original CAD assembly model.

CAD Import Errors
If a part geometry file is invalid or missing, the corresponding body cannot show in the Simscape Multibody visualization utility. If a CAD assembly model contains an unsupported constraint combination between bodies, Simscape Multibody software joins the bodies with a rigid connection. The rigid connection can take the form of a direct frame connection line, Rigid Transform (https://www.mathworks.com/help/physmod/sm/ref/rigidtransform.html) block, or Weld Joint (https://www.mathworks.com/help/physmod/sm/ref/weldjoint.html) block.
Rigid Connection Due to Unsupported Constraints

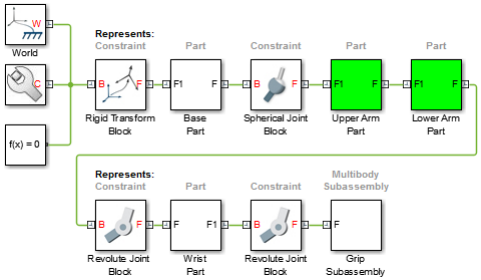
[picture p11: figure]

If Simscape Multibody software cannot translate a CAD constraint combination, it issues a warning message on the MATLAB command window identifying the affected bodies and their connection frames. For example:
Warning: The set of constraints between upperarm_1_RIGID and forearm_1_RIGID could not be mapped to a joint. A rigid connection has been added between port F
of upperarm_1_RIGID and port F1 or forearm_1_RIGID for these constraints.
Simplifying Model Topology
You can import a CAD model with a simplified topology. So that you can do this, the smimport function provides the ModelSimplification argument. You can set this argument to:
- bringJointsToTop to group each set of rigidly connected parts into a new subsystem and promote all joints to the top level of the model hierarchy.
- groupRigidBodies to group rigidly connected parts into subsystems (and leave joints in their original places in the model hierarchy).
- None to import the model as is, without simplification.
Use the bringJointsToTop or groupRigidBodies option if your CAD model has many rigidly connected components, such as nuts and bolts, that you prefer to group together—for example, to more intuitively grasp the key components of the model at a glance of the block diagram.
Use the bringJointsToTop option if your CAD model has joints inside subassemblies and you prefer to expose them at the top level—for example, to work with joint actuation and sensing signals without having to search for the joints inside different subsystems.
Note that model simplification is available for CAD import only. URDF models have flat topologies with little need for topology simplification.
Exercise 5: Mechatronic system design and modeling using Inventor-Simscape.
In this example, we will investigate a practical workflow for designing and modelling a mechatronic system using Autodesk Inventor and Simscape Multibody.

Design the mechanical System using Inventor and export it to Simscape Mutlibody
We first start by designing the mechanical system and drawing it using Autodesk Inventor 2017. Since this is a time-consuming process and the focus of this exercise is on Simscape Multibody, we will use an already assembled Autodesk Inventor model that we will download from the internet. Our target system for this exercise will be a 6-DOF robot.
1. Download the mechanical assembly using this link: https://grabcad.com/library/industrial-robot-12 (https://grabcad.com/library/industrial-robot-12)
Note: You need to have Autodesk Inventor 2017 to be able to open this assembly. Previous versions will not be able to open it.
2. The link contains an assembly for the mechanical structure of the robot. Follow the same steps as you did in Exercises 2 and 3 to export the assembly from Inventor to an XML file and import it into Simscape Multibody.
3. After you have imported the model you should end up with a model like this:

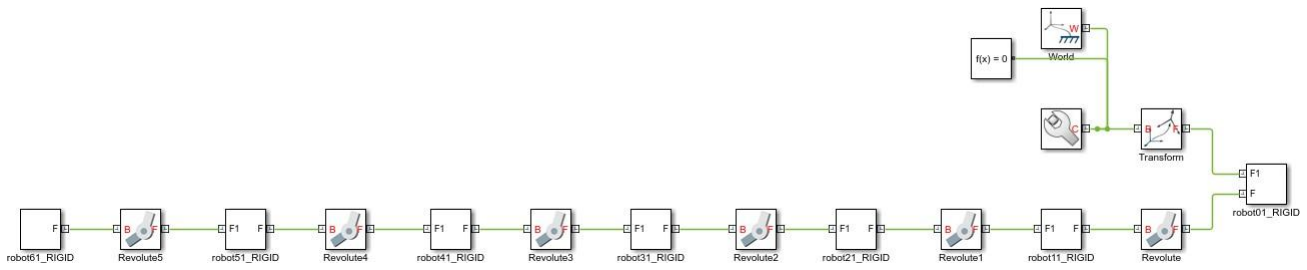
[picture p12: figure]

4. To view the imported model click on Simulation > Update Diagram you should see something
like | this:

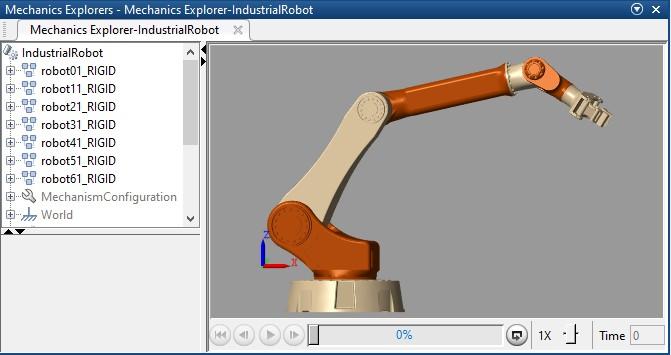
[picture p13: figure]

5. As with the case in Exercise 3, the view of the robot is different from that in Inventor. Adjust the view convention to get an isometric view similar to this:
6. Adjust the gravity of the environment by double clicking the “Machine configuration block”

Make sure that the gravity is acting in the negative Z-axis direction by setting the Gravity to [0 0 -9.80665]
7. Run the simulation and observe what happens to our robot.
The robot falls under the effect of gravity because we haven’t defined any actuators to maintain its position or control its motion. Also, the robot does not come to a stop no matter how long you run the simulation because no damping is defined in the system. We will address this in the next steps.
8. First, we will try to fix the position of the robot and later on, we will try to control its motion. To fix the position of the robot we must apply an actuation input to all the joints of the robot. Double click the first revolute joint named Revolute and from the joint dialogue under Actuation change the Motion to Provided by Input and the Torque to Automatically

Computed and press OK.

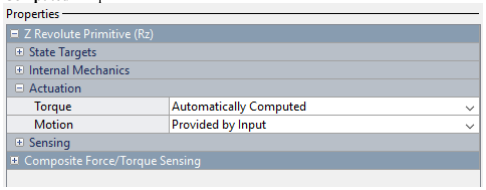
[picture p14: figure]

9. A new input port will appear in the joint block. It needs to be connected to a physical signal to represent the angle that we want the joint to move to. We can either use a S-PS block and provide a normal Simulink signal or instead we will use the simpler Constant PS block which is found under Simscape>Foundation Library>Physical signals>Sources>Constant PS. We will then connect the source block to our newly created input port:

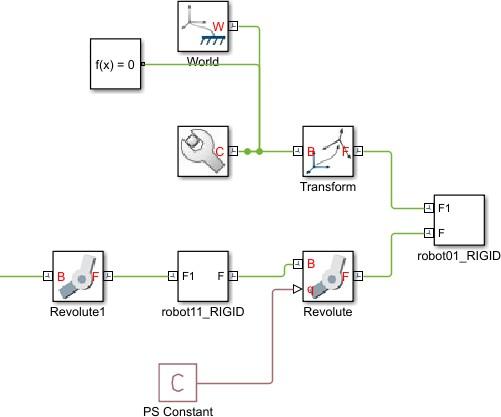
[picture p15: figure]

We will set the value of the constant to zero, to fix the robot at the zero position of the first joint.
10. Run the Simulation again and observe although the robot falls under gravity. It doesn’t rotate around the Z-axis because we fixed the first joint.
11. We need now to fix the rest the of the joints of the robot to hold the robot in its position. Repeat Steps 7 and 8 for the other Revolute joints in the mechanism.
12. Run the Simulation again, you should see the robot fixed in this orientation:

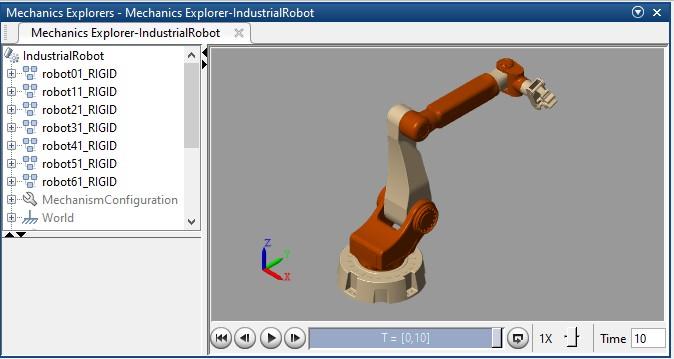
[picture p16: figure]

Why did the orientation of the robot change in this step from that of step 5?

13. We have provided a constant input position input to the joints. Lets examine the torque that we need to apply on the joints to keep the robot fixed in this position. Double click the first revolute joint named Revolute and from the joint dialogue under Sensing, check the box next to Actuation Torque. Repeat the same step for the joint Revolute 1.
14. Connect the newly created sensing ports as shown here:

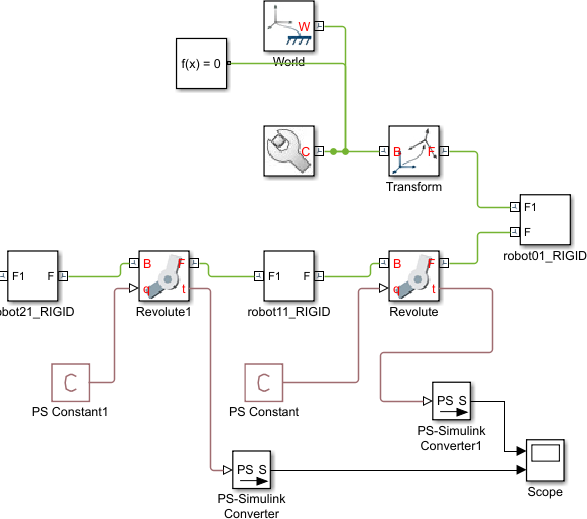
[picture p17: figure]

15. Run the simulation and observe the required actuation torques for both joints from the Scope. Comment on the values and what would affect them. Can you modify the orientation of the robot to minimize the actuator torque of the second joint?
16. Now that we have fixed the position of the robot we will try to move one of the joints. We can do this by changing the input of the first joint from PS Constant to an ordinary Sine wave block connected through a Simulink-PS block

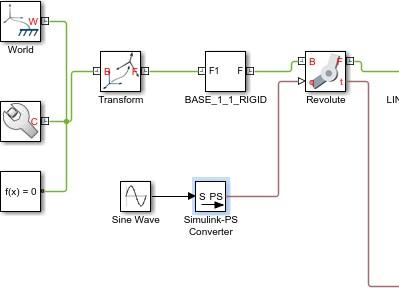
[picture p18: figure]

Important note: In order to provide a varying motion input signal you need to provide the derivatives of the signal also. You can do this by double clicking on the S PS block and under input handling provide Second-Order filtering.

17. Run the Simulation and observe the motion of the robot.
18. The robot moves according to the input signal which is an oscillating sine wave with frequency 1 rad/sec. Double click on the scope to see the torque required to achieve this motion profile for the first two joints:

Note that the torque at time zero is very high (about 5 × 10⁴ Nm). This is because we are suddenly forcing the robot to follow the motion. To fix this problem we need to adjust the Input filtering time constant in the S PS block. Set it to 0.1 sec as shown below:

19. Run the simulation again and observe the torque values through the scope. It should look like the

following (don’t forget to Autoscale the scope using ):

20. We can use the previous plot to estimate the minimum size of the motor that we need to move the joints. To achieve this motion profile, it seems that we need a motor that can provide a torque greater than 150 Nm for the first joint and 700 Nm for the second joint , but what about the angular velocity of the joint?
21. Add a scope to measure the velocity of the moving joint in rpm.
22. The scope should show a profile like this:

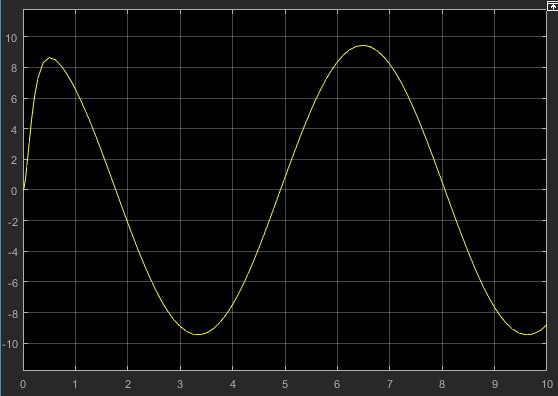
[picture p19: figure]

So it seems that we need to find a Servo motor that can supply a torque of at least 150Nm and with velocity more than 10 rpm. A Servo motor is just a DC motor placed in a closed position control loop with a controller. The following table is extracted from an ABB catalogue for DC motors, we need to select one of them which meets our specifications:

Table 1: Technical Specifications for ABB motor units, more details can be found in the mtors datasheet here: https://search-ext.abb.com/library/Download.aspx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 (https://search-ext.abb.com/library/Download.aspx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)

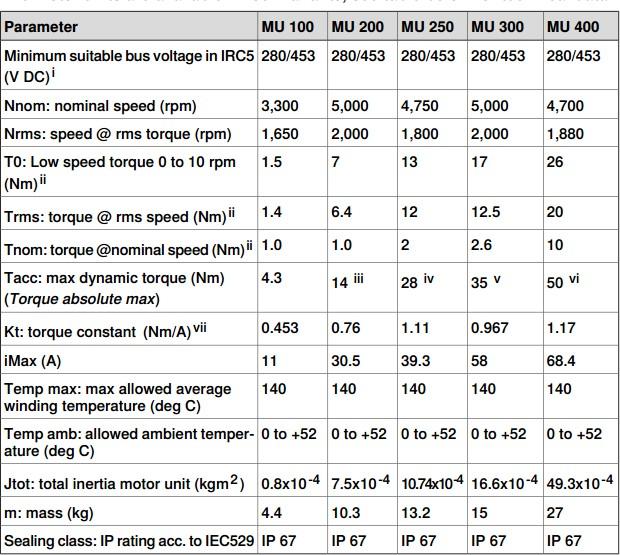
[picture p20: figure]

The nominal and speeds of all the motors are more than 100-250 times our target value, at the same time the maximum torque that they could provide is a lot less than our target value. A typical solution for this problem is to use a geared DC motor which has a speed reducing gearbox mounted on the motor. If we consider a gear ratio of 200, the motor (MU200) would be enough for our purpose (for the sinewave motion profile). It has stall torque (Low speed torque) of 7 Nm which if multiplied by our target gearbox ratio gives 1400 Nm.

23. The selected motor must also meet root mean square torque (Trms) of the target motion profile. To estimate the Trms, we need to export the torque profile of the first joint to MATLAB and use the function rms to estimate Trms. Use a Sinks>To Workspace block to export the torque of the first joint to a variable called T1, then use the rms function to estimate Trms. Does the MU200 meet the required rms Troque?:
24. As an initial trial we will assume that this motor is suitable for all the joints and we will use it to actuate the six joints of the robot.
25. Don’t forget to save your model!
26. To include the selected geared DC motor in our model, we will start by constructing the closed loop control loop which is necessary to convert it to a Servo motor. For the first joint (named “Revolute 2”) under Sensing check the box next to Position. Under Actuation change the Motion to Automatically Computed and the Torque to Provided by Input and press OK. Note: This is the opposite to what we did in Step 7 because we are going to specify the torque input this time.

27. Construct the closed loop between the two newly created ports as shown below:

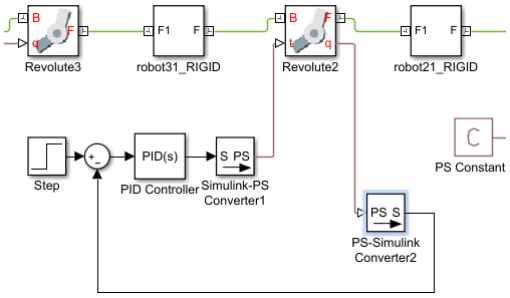
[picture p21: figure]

28. Leave the values of the newly added Step and PID Controller to their default values and run the simulation. Observe the third joint moves randomly; this is because we haven’t tuned the controller. We will not tune the controller now, instead, note that we are applying the output of the controller directly as the torque input of the joints. In reality, this is done using our selected DC motor. In the next steps we will add the dynamics of the DC motor to our model.
29. First, we will create a subsystem for our Servo motor. Select the closed loop as shown below:

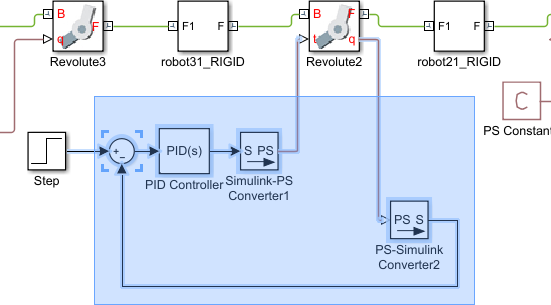
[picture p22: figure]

30. Right click on the selected components and select Create Subsystem from selection. Rename the created subsystem to Servo double click on it to open.
31. Reorganize the Servo subsystem and rename the input ports as shown in the figure below

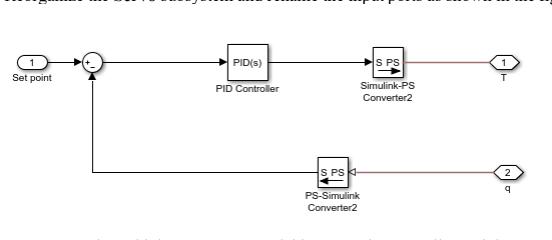
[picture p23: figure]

32. We now need to add the DC motor model between the controller and the torque output (T). Grab the following blocks into our subsystem:

Block | Location
DC Motor | Simscape>Electronics>Actuatos & Drives>Rotational Actuators
Controlled Voltage Source | Simscape>Foundation Library>Electrical>Electrical Sources
Electrical Reference | Simscape>Foundation Library>Electrical>Electrical Elements
Mechanical Rotational Reference | Simscape>Foundation Library>Mechanical> Rotational Elements
Ideal Torque Sensor | Simscape>Foundation Library>Mechanical>Mechanical Sensors
Gearbox | Simscape>Foundation Library>Mechanical>Mechanisms

Try connecting these blocks to construct a model of the DC motor between the controller and the Torque port (T). The correct connections are shown in the next page.

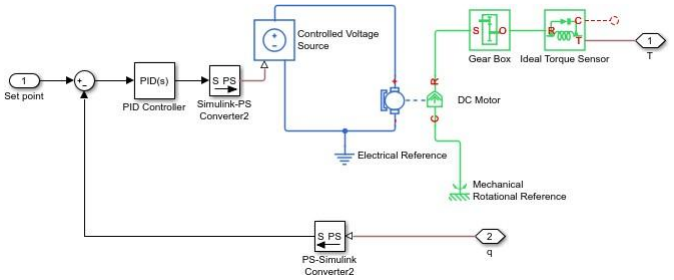
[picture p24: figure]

33. In the connection shown above the torque measured by the Ideal torque sensor (The Motor torque) is applied directly to the joint. This represents a one way coupling in which only the motor affects the robot mechanism, but the mechanism has no effect on the motor. To simulate the effect of the mechanism on the motor we will add an Ideal Angular Velocity Source. It is found under Simscape>Foundation Library>Mechanical>Mechanical Sources and connect it to our motor as shown below:

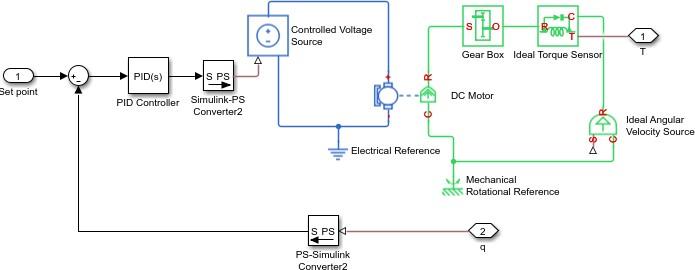
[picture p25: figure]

34. The velocity signal for the angular velocity source will come from the joint so we need first to create a Connection port for it in our subsystem you can find the physical Connection Port block under Simscape>Utilities. Rename it to w and connected to the Signal port of the velocity source:

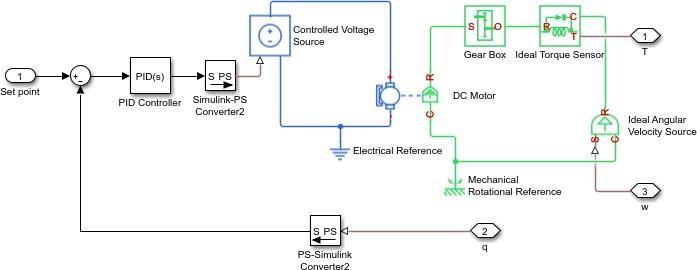
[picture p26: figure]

35. Exit the Servo Subsystem and double click on our target Revolute joint “Revolute 2” and under Sensing check the box next to velocity. Then connect the two “w” ports of the Servo and the revolute joint.


36. If you try to run the simulation now, you will notice that the third joint in the robot doesn’t go to the desired position. This is because:
1. We didn’t tune the PID controller.
2. We didn’t enter practical values for the DC motor properties or the gearbox.
37. Open the Servo subsystem and use the table in step 22 to input the properties of the DC motor. We will use the MU 200 Model with a maximum voltage of 450 V. Also from the ABB datasheet, this model has a winding resistance of 15 ohm and inductance of 1.2 mH.
38. In the PID Controller block change the proportional gain (P) to 800 and the Integral gain (I) to zero.
39. Exit the Servo subsystem. Try running the model with a setpoint of pi/4 specified in Final value for the Step block.
The system seems to stabilize to a certain point after oscillating for a while.
40. To have a closer look on the performance of our PID controller. Open the Servo block again and add two scopes named “Angle” and “Control Effort”. Connect them as shown below:


41. Three problems exist with our controller:
1. From the left graph, the yellow curve representing the actual angle of the joint does not reach the blue curve representing the set point. The controller, thus has a large steady state error.
2. The actual angle doesn’t start from the set point of (0), instead it starts from -2.3 rad.
3. The right graph represents the controller effort, which is the applied voltage on the DC motor in our system. At time 0, the voltage is 1700 volts which is more than the maximum voltage that our motor can handle (450 volts). In practice, that would burn the used motor.
42. You can address each problem by:
1. Tuning the controller to at least include an integral action. Example tuning values are shown below:


2. Limit the output of the controller so that it doesn’t exceed ±450 V. This can be done from the PID Advanced tab of the PID controller.
3. Specify the initial position of the joint to be zero, this can be done by double clicking the joint “Revolute 2” and set State Targets>Set Position Target>Value to zero degrees. You may want to give some time for the controller output to settle before applying the step input. This can be done by changing the value of the step time in the Step block.
43. We have used the first joint torque as a method to select our motor; however, motors are usually selected for the required motor torque and not the joint torque as they might differ. Lets check that the required motor torque can be satisfied by our motor. Add a Torque Sensor to measure the rms and peak torque of the DC motor in the Servo block. Can the M200 motor supply the actual torque needed to move this joint with the selected profile?

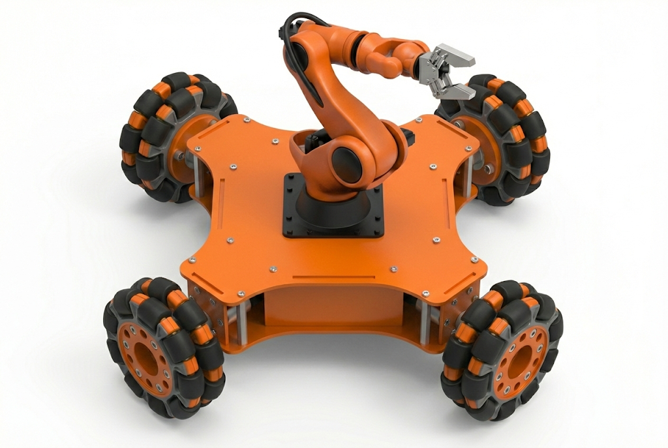
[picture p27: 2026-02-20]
_assets/Pasted image 20260212165008.png

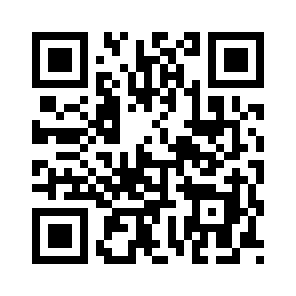
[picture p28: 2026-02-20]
_assets/Pasted Image 20260209043258_688.png

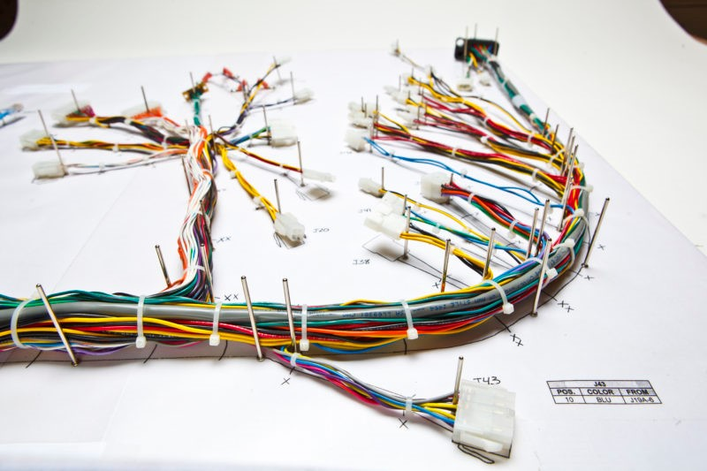
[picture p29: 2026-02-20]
_assets/Pasted image 20260209155549.png

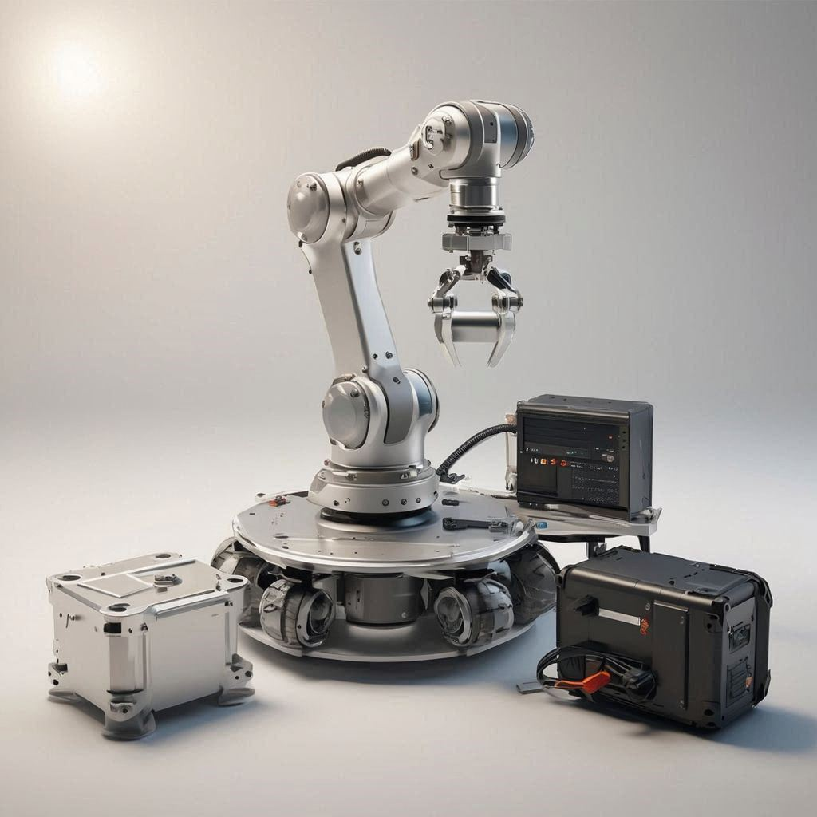
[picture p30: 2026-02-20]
_assets/Pasted image 20260209041734.png

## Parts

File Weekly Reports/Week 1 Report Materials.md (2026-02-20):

## Conceptual Design
- [[General Concepts]]
- [[Conceptual Design]]
### Functional Block Diagrams
- System
	- [[System]]
- Arm
	- [[Arm v0]]
	- [[Arm v1]]
	- [[Arm v2]]
### TRIZ
- [[Manipulator_Module_TRIZ.xlsx]]
- [[TRIZ Worksheet v2.xlsx]]

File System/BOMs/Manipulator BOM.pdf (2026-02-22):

# Manipulator Module Initial Bill of Materials (BOM)

## MCT333 Mechatronic System Design

## 1 Manipulator Initial BOM

### 1.1 Arm Structure & Mechanics BOM

- Standardized modular base mounting plate (laser cut aluminum or 3D printed PETG/ABS)
- Quick-release latch mechanism and chamfered alignment pins
- Arm linkages (Carbon fiber tubes and/or structurally ribbed 3D printed components)
- Base joint thrust bearing (to support horizontal panning under vertical moment load)
- Gripper chassis and V-shaped interlocking jaws
- High-friction silicone grip pads (for 5 × 5 × 5 cm cubes)
- Offset camera mounting bracket
- Cable routing: Drag chains, spiral wrap, and zip ties
- Fasteners set:

– M2/M2.5 screws and nuts (for servo horns and camera mounting)

– M3/M4 screws, nylon lock nuts, and washers (for main structural joints)

– Medium-strength threadlocker

### 1.2 Actuation & Electronics BOM

- Smart serial servos (×3) (e.g., Dynamixel or Feetech, with integrated absolute encoders and PID)
- Micro PWM servo (×1) (for gripper actuation)
- Aluminum servo horns and heavy-duty structural brackets

1

- Custom Manipulator PCB (incorporating MCU, buck converters, and CAN/RS-485 transceiver)
- End-effector RGB Camera (USB or MIPI interface for QR code reading)
- Active LED ring light (for consistent QR code illumination)
- High-flexibility silicone wiring (3-wire/4-wire daisy chain cables for smart servos)
- Modular interface connectors (Plug-and-Play interface):

– Power: XT60 or Anderson Powerpole connector

– Data: JST-SM or locking Aviation plug

2

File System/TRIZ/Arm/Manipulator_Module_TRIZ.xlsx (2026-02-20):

Mechanical Arm Structure
Case | Problem | Engineering Contradiction | TRIZ Principle | Engineering Solution | Expected Benefit
Case 1 | Arm must reach 40 cm but remain lightweight. | Increasing reach increases mass and bending moment. | Principle 40 – Composite Materials | Use lightweight aluminum links with 3D printed joints. | Extended reach with reduced weight.
Case 2 | High torque required at base joint. | Increasing motor torque increases size and weight. | Principle 8 – Anti-weight | Add spring assistance or counterweight. | Reduced motor load and improved efficiency.
Joint Actuation Subsystem
Case | Problem | Engineering Contradiction | TRIZ Principle | Engineering Solution | Expected Benefit
Case 1 | Backlash reduces positioning precision. | Gear reduction improves torque but increases backlash. | Principle 24 – Intermediary | Use high-quality planetary gearbox. | Improved repeatability.
Gripper Subsystem
Case | Problem | Engineering Contradiction | TRIZ Principle | Engineering Solution | Expected Benefit
Case 1 | Cube slips during grasp. | Increasing grip force may damage cube. | Principle 31 – Porous Materials | Add rubber pads on fingers. | Secure grip without excessive force.
Case 2 | Cube alignment uncertainty. | Rigid fingers reduce tolerance to misalignment. | Principle 14 – Curvature | Design curved or V-shaped fingers. | Self-centering grasp.
Kinematics & Trajectory Planning
Case | Problem | Engineering Contradiction | TRIZ Principle | Engineering Solution | Expected Benefit
Case 1 | Positioning error during pick and place. | Faster motion reduces accuracy. | Principle 10 – Preliminary Action, Principle 23 – Feedback | Use predefined trajectory profiles with encoder feedback. | Improved repeatability.
Object Detection Integration
Case | Problem | Engineering Contradiction | TRIZ Principle | Engineering Solution | Expected Benefit
Case 1 | QR detection failure. | Fast detection increases error probability. | Principle 23 – Feedback | Validate QR detection multiple times. | Reduced false detection.
Storage Bin Mechanism
Case | Problem | Engineering Contradiction | TRIZ Principle | Engineering Solution | Expected Benefit
Case 1 | Cubes fall during robot motion. | Open bins reduce retention security. | Principle 3 – Local Quality | Design separate RGB compartments with raised walls. | Secure storage.
Arm Safety & Limit Protection
Case | Problem | Engineering Contradiction | TRIZ Principle | Engineering Solution | Expected Benefit
Case 1 | Arm exceeds mechanical limits. | Large motion range increases collision risk. | Principle 11 – Beforehand Cushioning | Add limit switches and software constraints. | Prevents structural damage.

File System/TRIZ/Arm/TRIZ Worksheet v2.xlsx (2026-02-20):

Category | Case | Problem | Engineering Contradiction | TRIZ Principle | Engineering Solution | Expected Benefit
Mechanical Arm Structure | Case 1 | Arm must reach 40 cm but remain lightweight. | Increasing reach increases mass and bending moment. | Principle 40 – Composite Materials | Use lightweight aluminum links with 3D printed joints. | Extended reach with reduced weight.
Mechanical Arm Structure | Case 2 | High torque required at base joint. | Increasing motor torque increases size and weight. | Principle 8 – Anti-weight | Add spring assistance or counterweight. | Reduced motor load and improved efficiency.
Mechanical Arm Structure | Case 3 | Arm must fit in 50x50x70 start box but reach distant targets. | Compact volume limits operational reach. | Principle 7 – Nested Doll | Use a telescopic link design or a folding SCARA architecture. | Meets size constraints without sacrificing workspace.
Joint Actuation Subsystem | Case 1 | Backlash reduces positioning precision. | Gear reduction improves torque but increases backlash. | Principle 24 – Intermediary | Use high-quality planetary gearbox. | Improved repeatability.
Joint Actuation Subsystem | Case 2 | Wire fatigue and tangling at rotating joints. | Increased range of motion reduces cable reliability. | Principle 17 – Another Dimension | Route cables through hollow-shaft actuators or use slip rings. | Prevents wire breakage during matches.
Joint Actuation Subsystem | Case 3 | Power spikes from simultaneous joint motion cause logic brownouts. | High mechanical power disrupts stable electrical signals. | Principle 11 – Beforehand Cushioning | Isolate logic/motor power rails and add large capacitor banks. | System stability and continuous operation.
Gripper Subsystem | Case 1 | Cube slips during grasp. | Increasing grip force may damage cube. | Principle 31 – Porous Materials | Add rubber pads on fingers. | Secure grip without excessive force.
Gripper Subsystem | Case 2 | Cube alignment uncertainty. | Rigid fingers reduce tolerance to misalignment. | Principle 14 – Curvature | Design curved or V-shaped fingers. | Self-centering grasp.
Gripper Subsystem | Case 3 | Camera view is obstructed by gripper fingers during approach. | Grasp proximity limits visual field of view. | Principle 2 – Taking Out / Separation | Mount camera on an offset bracket angled at the focal point. | Clear QR scanning while maintaining grip readiness.
Gripper Subsystem | Case 4 | Ambient lighting varies causing QR scan failures. | Image quality suffers due to environmental unpredictability. | Principle 32 – Color Changes (Optical) | Add an active LED ring light around the camera lens. | Consistent lighting for faster QR decoding.
Kinematics & Trajectory Planning | Case 1 | Positioning error during pick and place. | Faster motion reduces accuracy. | Principle 10 – Preliminary Action, Principle 23 – Feedback | Use predefined trajectory profiles with encoder feedback. | Improved repeatability.
Kinematics & Trajectory Planning | Case 2 | Dropping cubes into specific bins requires slow 3D collision avoidance. | Task speed conflicts with kinematic complexity. | Principle 10 – Preliminary Action | Design passive angled chutes so the arm drops all cubes at one safe overhead zone. | Faster cycle times and simpler IK calculations.
Object Detection Integration | Case 1 | QR detection failure. | Fast detection increases error probability. | Principle 23 – Feedback | Validate QR detection multiple times. | Reduced false detection.
Storage Bin Mechanism | Case 1 | Cubes fall during robot motion. | Open bins reduce retention security. | Principle 3 – Local Quality | Design separate RGB compartments with raised walls. | Secure storage.
Arm Safety & Limit Protection | Case 1 | Arm exceeds mechanical limits. | Large motion range increases collision risk. | Principle 11 – Beforehand Cushioning | Add limit switches and software constraints. | Prevents structural damage.
Modularity & Plug-and-Play | Case 1 | Connecting power/data/mechanics takes >5 minutes. | Secure connections require time-consuming manual assembly. | Principle 5 – Merging | Combine power data (pogo pins) and mechanical lock into a single latch plate. | Sub-1-minute plug-and-play integration.
Modularity & Plug-and-Play | Case 2 | Misalignment when attaching the arm module. | High precision positioning slows down manual assembly. | Principle 14 – Spheroidality / Curvature | Use chamfered guide pins and V-grooves on the mounting plate. | Foolproof and rapid self-centering docking.

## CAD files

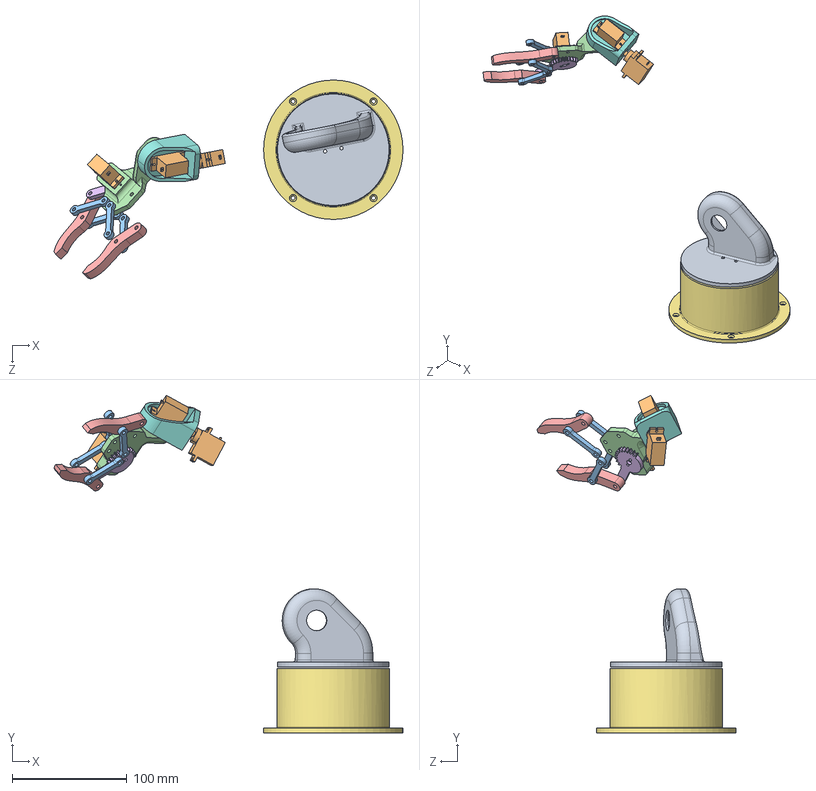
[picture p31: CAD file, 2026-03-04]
Mechanical/robotic_arm_5dof/ASSEMBLY/FINAL ROBOT ASSEMBLY.SLDASM
303.6 x 293.6 x 173.0 mm
ARM 03
BASE OF ROBOTIC ARM
GEAR 1
GRIPPER x 2
GRIPPER BASE
GRIPPER LINK x 4
SERVO MOTOR MICRO 9G x 3
WAIST

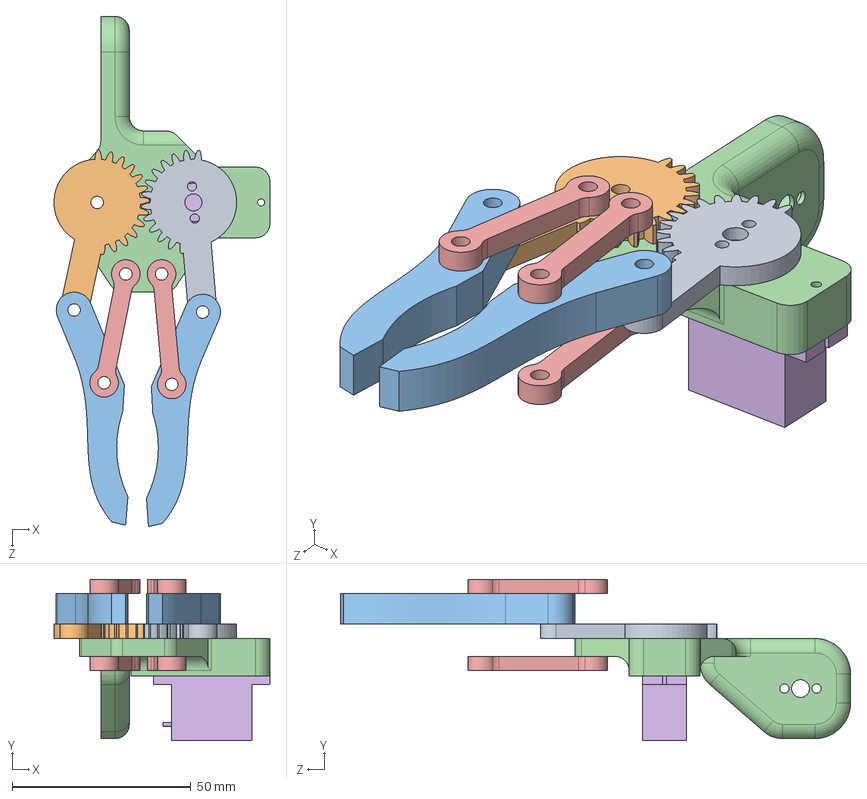
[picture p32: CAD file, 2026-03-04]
Mechanical/robotic_arm_5dof/PARTS/GRIPPER ASSEMBLY.SLDASM
60.4 x 45.0 x 142.6 mm
GEAR 1
GEAR 2
GRIPPER x 2
GRIPPER BASE
GRIPPER LINK x 4
SERVO MOTOR MICRO 9G

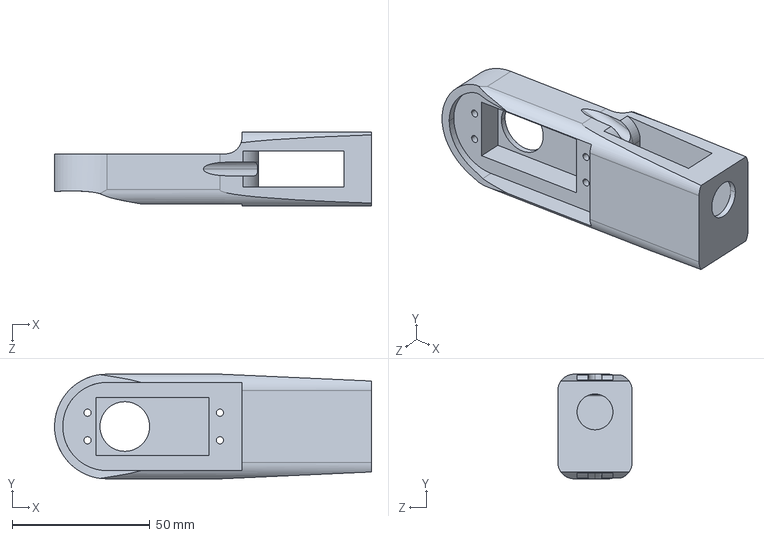
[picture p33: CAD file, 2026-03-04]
Control/robotic_arm_5dof_matlab/ARM 02_Default_sldprt.STEP
115.0 x 38.0 x 27.0 mm

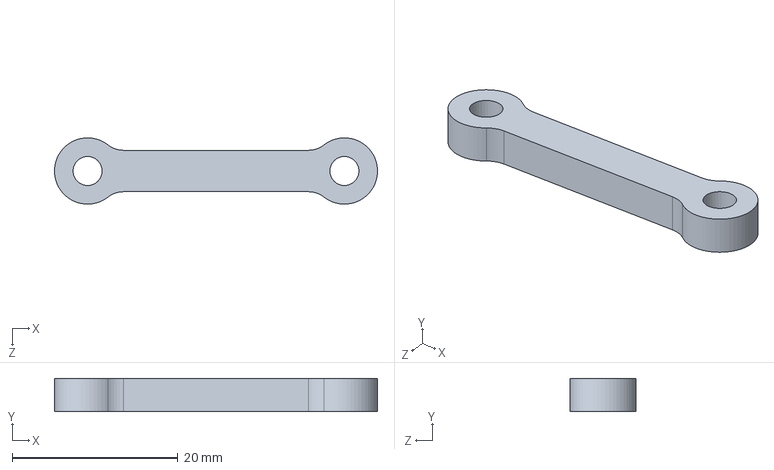
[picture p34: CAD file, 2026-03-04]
Mechanical/robotic_arm_5dof/PARTS/GRIPPER LINK.SLDPRT
39.0 x 4.00 x 7.99 mm

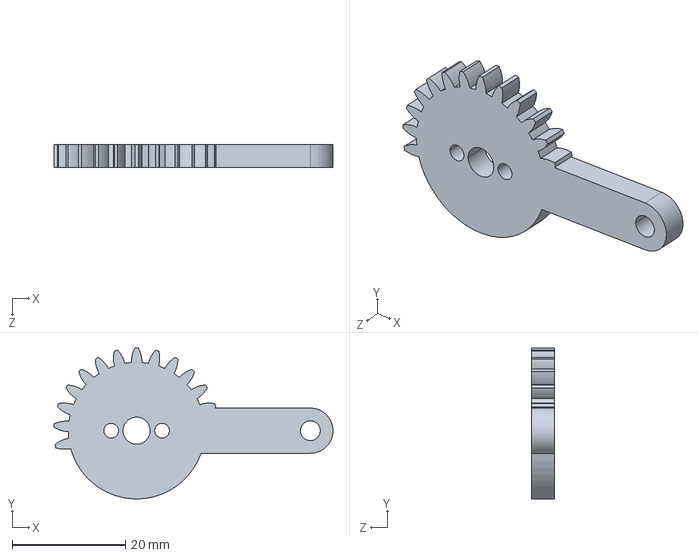
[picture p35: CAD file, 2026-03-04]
Control/robotic_arm_5dof_matlab/GEAR 1_Default_sldprt.STEP
49.4 x 26.7 x 4.00 mm

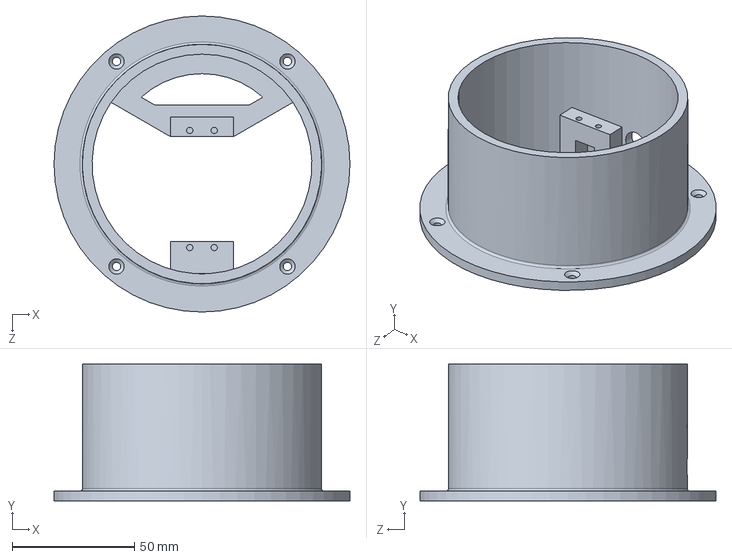
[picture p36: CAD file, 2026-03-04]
Mechanical/robotic_arm_5dof/PARTS/BASE OF ROBOTIC ARM.SLDPRT
121.2 x 56.0 x 121.2 mm

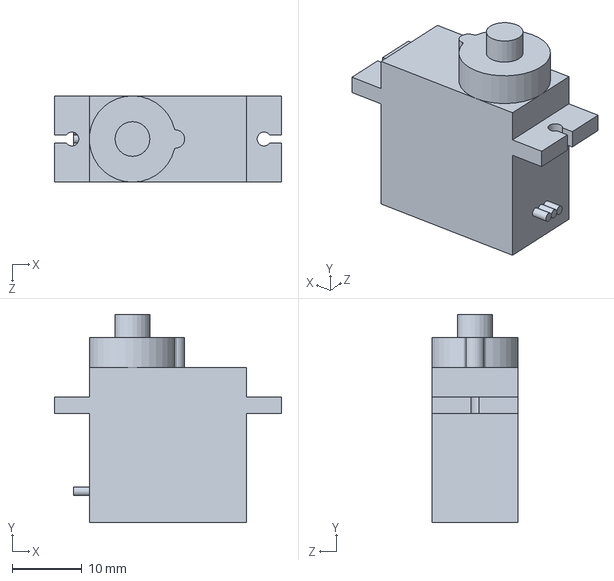
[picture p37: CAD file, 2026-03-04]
Mechanical/robotic_arm_5dof/PARTS/SERVO MOTOR MICRO 9G.SLDPRT
32.6 x 29.9 x 12.4 mm

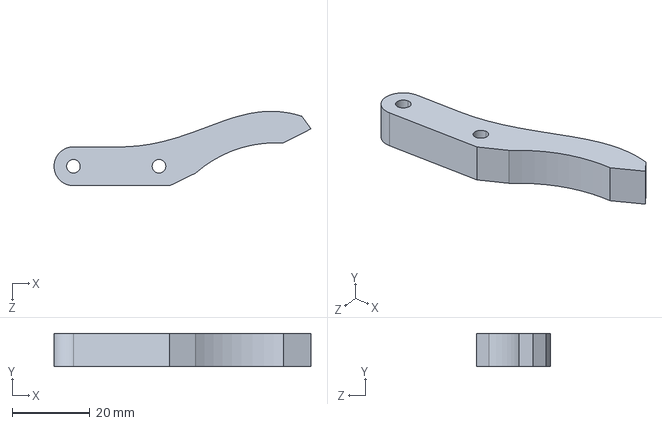
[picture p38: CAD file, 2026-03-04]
Control/robotic_arm_5dof_matlab/GRIPPER_Default_sldprt.STEP
66.1 x 8.50 x 19.1 mm

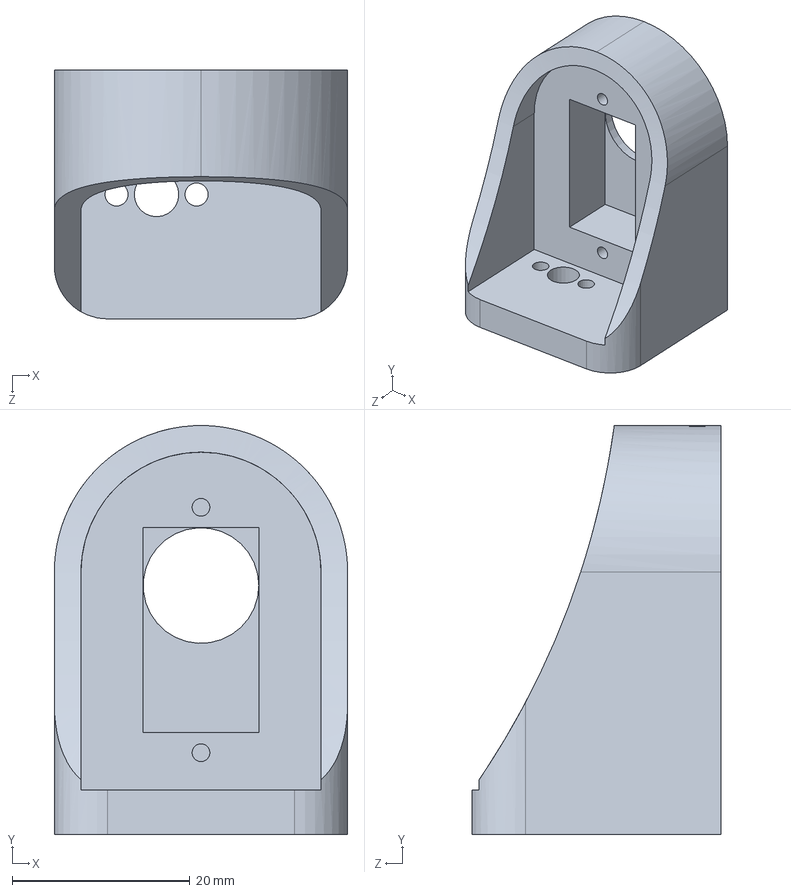
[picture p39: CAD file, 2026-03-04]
Mechanical/robotic_arm_5dof/PARTS/ARM 03.SLDPRT
33.0 x 46.0 x 28.0 mm

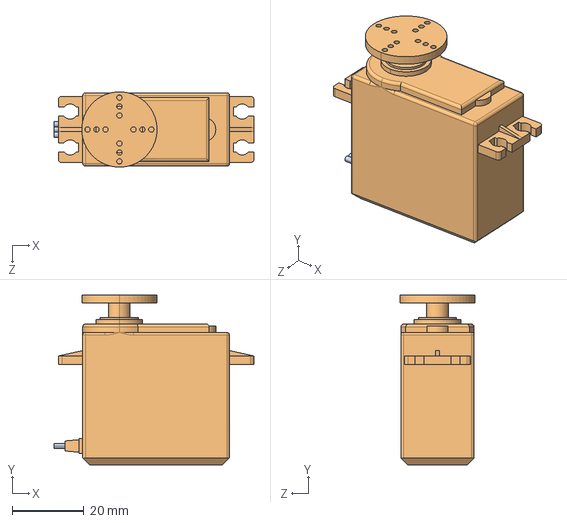
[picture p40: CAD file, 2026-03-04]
Control/robotic_arm_5dof_matlab/SERVO MOTOR MG996R_Default_sldprt.STEP
55.8 x 47.4 x 21.0 mm

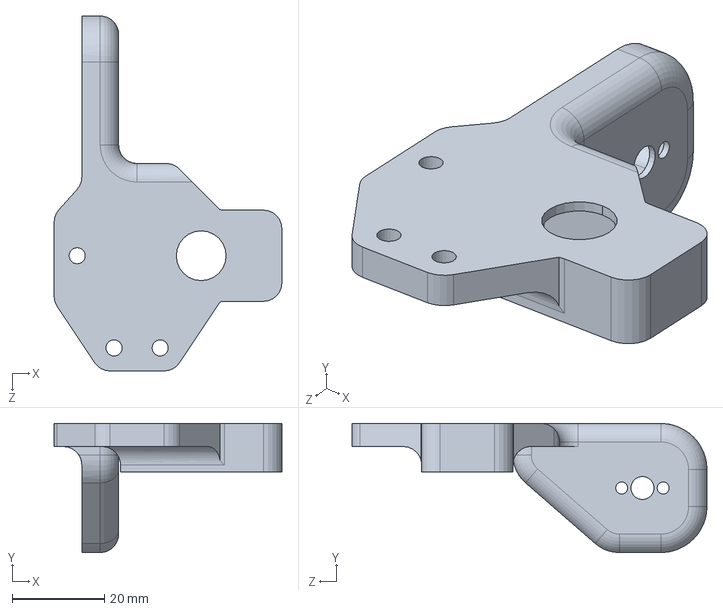
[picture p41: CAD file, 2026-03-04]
Mechanical/robotic_arm_5dof/PARTS/GRIPPER BASE.SLDPRT
49.4 x 28.0 x 77.0 mm

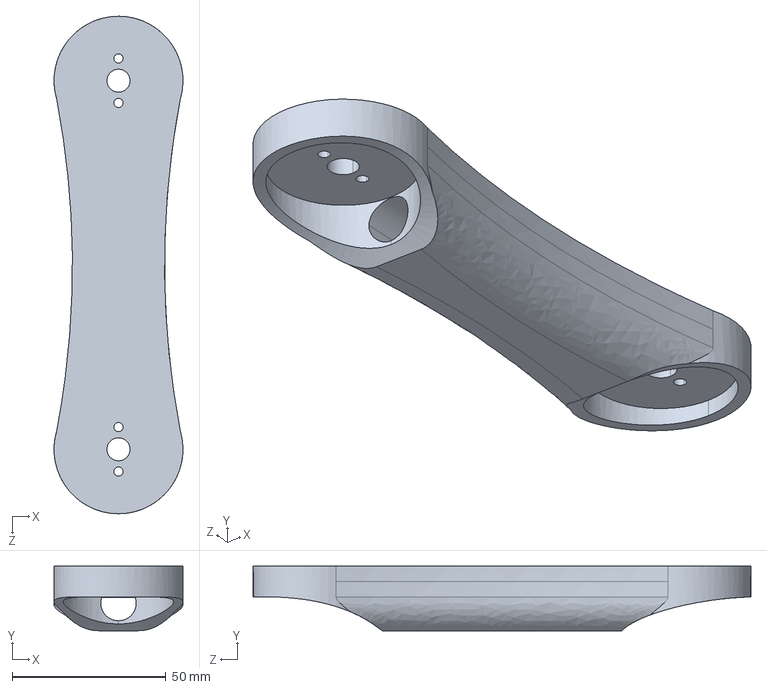
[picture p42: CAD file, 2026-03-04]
Control/robotic_arm_5dof_matlab/ARM 01_Default_sldprt.STEP
42.0 x 21.0 x 162.0 mm

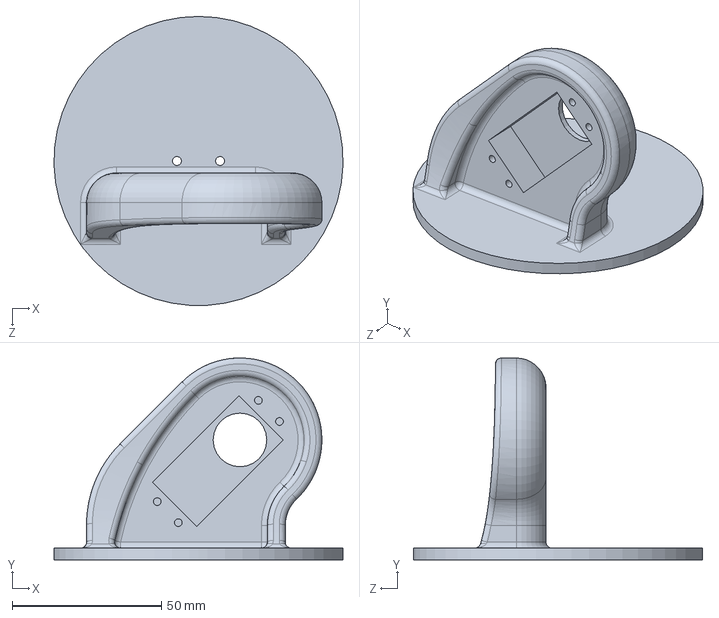
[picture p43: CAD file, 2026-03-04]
Mechanical/robotic_arm_5dof/PARTS/WAIST.SLDPRT
97.0 x 67.8 x 97.0 mm

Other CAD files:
Control/robotic_arm_5dof_matlab/GRIPPER LINK_Default_sldprt.STEP
Control/robotic_arm_5dof_matlab/SERVO MOTOR MICRO 9G_Default_sldprt.STEP
Mechanical/robotic_arm_5dof/PARTS/GEAR 1.SLDPRT
Control/robotic_arm_5dof_matlab/WAIST_Default_sldprt.STEP
Mechanical/robotic_arm_5dof/PARTS/GRIPPER.SLDPRT
Control/robotic_arm_5dof_matlab/ARM 03_Default_sldprt.STEP
Control/robotic_arm_5dof_matlab/BASE OF ROBOTIC ARM_Default_sldprt.STEP
Control/robotic_arm_5dof_matlab/GEAR 2_Default_sldprt.STEP
Control/robotic_arm_5dof_matlab/GRIPPER BASE_Default_sldprt.STEP
Mechanical/robotic_arm_5dof/PARTS/ARM 01.SLDPRT
Mechanical/robotic_arm_5dof/PARTS/ARM 02.SLDPRT
Mechanical/robotic_arm_5dof/PARTS/GEAR 2.SLDPRT
Mechanical/robotic_arm_5dof/PARTS/SERVO MOTOR MG996R.SLDPRT

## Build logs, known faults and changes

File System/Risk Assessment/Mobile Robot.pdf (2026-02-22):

# Mobile Robot Risk Assessment Report

## Risk Assessment Report

This document outlines the risk assessment process and results for the current project/operation. The goal is to identify, analyze, and evaluate potential risks to minimize their negative impact.

## Risk Assessment Matrix

The risk score is calculated by multiplying the Likelihood and Impact ratings.

Likelihood (L) | Description | Impact (I) | Description | Risk Score (R) = L x I | Risk Level
1 | Rare | 1 | Insignificant | 1-2 | Low
2 | Unlikely | 2 | Minor | 3-6 | Medium
3 | Moderate | 3 | Moderate | 7-12 | High
4 | Likely | 4 | Major | 13-16 | Extreme
5 | Almost Certain | 5 | Catastrophic

## General Identified Risks

The following table details the risks identified, their assigned Likelihood and Impact ratings, and the resulting Risk Score.

Risk ID | Risk Descrip-tion | Likelihood (L) | Impact (I) | Risk Score (R) | Level | Mitigation Strategy
R001 | Odometry Drift / Head-ing Loss | 4 | 4 | 16 | Extreme | Implement sensor fu-sion combining wheel encoders with the IMU for heading stabiliza-tion. Tune the kine-matic controller to han-dle slip.

R002 | Vision System Failure (Light-ing/Blur) | 3 | 5 | 15 | Extreme | Stop the robot com-pletely before scanning the QR code. Im-plement auto-exposure in the camera pipeline and validate the percep-tion approach on varied recorded data.
R003 | Track Bound-ary Collisions | 3 | 3 | 9 | High | Implement lane detec-tion via camera. Add proximity/ToF sensors as optional backups. Note that boundary crossings incur a -3 point penalty, and collisions -5 points.
R004 | Unstable PID (oscillation) | 4 | 3 | 12 | High | Structured tuning + real-time data logging
R005 | State machine logic bug/hang | 2 | 5 | 10 | High | Simulation testing + timeout ”fail-safe” states
R006 | Communication failure be-tween modules | 3 | 4 | 12 | High | Heartbeat timeout + watchdog timer imple-mentation
R007 | Weight ex-ceeds 10kg limit | 1 | 5 | 5 | Medium | Continuous mass track-ing in CAD BOM
R008 | Dimensions exceed folded limit | 1 | 5 | 5 | Medium | Virtual envelope verifi-cation in CAD
R009 | Late integra-tion failure | 4 | 4 | 16 | Critical | Mandatory weekly sub-system integration tests

## Power & Electronics

## Identified Risks in Power & Electronics

The following table details the risks identified, their assigned Likelihood and Impact ratings, and the resulting Risk Score.

Risk ID | Risk Description | Likelihood (L) | Impact (I) | Risk Score (R) | Mitigation Strategy
R001 | Short Circuits / Exposed Wiring | 2 | 5 | 10 | Use proper harnessing, strain relief, and cable management. Ensure all PCBs are fixed inside an enclosure with insulated terminals

R002 | Battery Over-Discharge | 3 | 5 | 15 | PMS undervoltage lockout
R003 | Battery Over-Charge | 2 | 4 | 8 | Certified charging module
R004 | Battery overcur-rent | 4 | 3 | 12 | Main fuse + PMS protec-tion
R005 | Reverse polarity | 3 | 4 | 12 | Reverse polarity protection diodes or MOSFETs on custom PCBs
R006 | Charging while running | 4 | 4 | 16 | Charge interlock + label-ing
R007 | Communication Bus Interference | 4 | 3 | 12 | Use twisted-pair cables for data lines, keep logic wires away from high-current motor wires, and implement a software ”heartbeat” to detect connection drops
R008 | Main Fuse Blow-ing Mid-Run | 3 | 4 | 12 | Calculate total peak stall current for all drive and arm motors. Select a correctly rated main fuse and verify margins during Phase 3 simulation
R009 | BMS failure | 2 | 4 | 8 | Qualified components
R010 | Uneven power routing | 4 | 4 | 16 | Proper power planes
R011 | High inrush cur-rent | 3 | 5 | 15 | Soft-start / NTC
R012 | Ground loop / poor return | 3 | 5 | 15 | Star grounding scheme
R013 | Regulator over-heating | 4 | 4 | 16 | Thermal design + heatsinking
R014 | High output rip-ple | 2 | 5 | 10 | LC filtering + decoupling
R015 | Regulator dropout | 3 | 5 | 15 | Proper headroom design
R016 | Wrong regulator sizing | 2 | 6 | 12 | Power budget margin 30%
R017 | PCB trace over-heating | 3 | 5 | 15 | Wide copper pours
R018 | Connector over-heating | 3 | 5 | 15 | Proper current rating
R019 | Fuse improperly rated | 2 | 4 | 8 | Correct fuse sizing

## Electromechanical

## Mechanical Risks

Risk ID | Risk Descrip-tion | Likelihood (L) | Impact (I) | Risk Score (R) | Risk Level | Mitigation Strategy
R001 | Chassis bend-ing under load | 3 | 4 | 12 | High | Perform structural esti-mation, add ribs, use thicker plate
R002 | High center of gravity (battery place-ment) | 3 | 5 | 15 | Extreme | Mount battery at lowest point, widen base foot-print
R003 | Wheel mis-alignment | 4 | 4 | 16 | Extreme | slotted adjustment holes
R004 | Loose fasten-ers due to vibration | 4 | 3 | 12 | High | Lock nuts, threadlocker

## Electromechanical Risks

Risk ID | Risk Descrip-tion | Likelihood (L) | Impact (I) | Risk Score (R) | Risk Level | Mitigation Strategy
R005 | Motor under-sized (torque insufficient) | 3 | 5 | 15 | Extreme | Full torque calculation including (friction + margin)
R006 | Wheel slipping (low friction rollers) | 4 | 4 | 16 | Extreme | Use rubber omni wheels, control acceler-ation ramp
R007 | Unequal motor speeds → rota-tion drift | 4 | 4 | 16 | Extreme | Closed-loop control us-ing encoders
R008 | Overheating motor drivers | 2 | 4 | 8 | High | Proper Powertrain eval-uation and circuit regu-lation

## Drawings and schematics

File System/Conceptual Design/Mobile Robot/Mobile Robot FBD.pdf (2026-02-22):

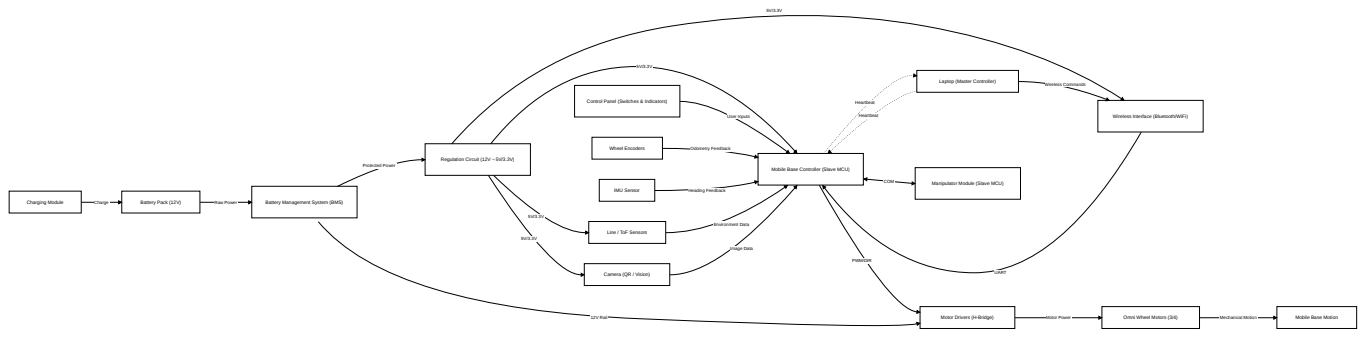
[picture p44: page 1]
Charging Module; Battery Pack (12V); Battery Management System (BMS); Regulation Circuit (12V→5V/3.3V); Omni Wheel Motors (3/4); Mobile Base Motion; Wheel Encoders; IMU Sensor; Manipulator Module (Slave MCU); Charge; Raw Power; 12V Rail; Protected Power; Wireless Commands; UART; User Inputs; PWM/DIR; Motor Power; Mechanical Motion; Odometry Feedback; Heading Feedback; Environment Data; Image Data; COM; Heartbeat

Laptop (Master Controller)

Control Panel (Switches & Indicators)

Wireless Interface (Bluetooth/WiFi)

Mobile Base Controller (Slave MCU)

Line / ToF Sensors

Camera (QR / Vision)

Motor Drivers (H-Bridge)

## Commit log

2026-02-20 dev: Add GitHub open gate and organize notes
    [Manipulator_Module_TRIZ.xlsx, TRIZ Worksheet v2.xlsx]
2026-03-04 Revert submodules to folders
    [ARM 01.SLDPRT, ARM 01_Default_sldprt.STEP, ARM 02.SLDPRT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]
2026-03-13 dev: Add model controller to control and arm using servo motors' torques
